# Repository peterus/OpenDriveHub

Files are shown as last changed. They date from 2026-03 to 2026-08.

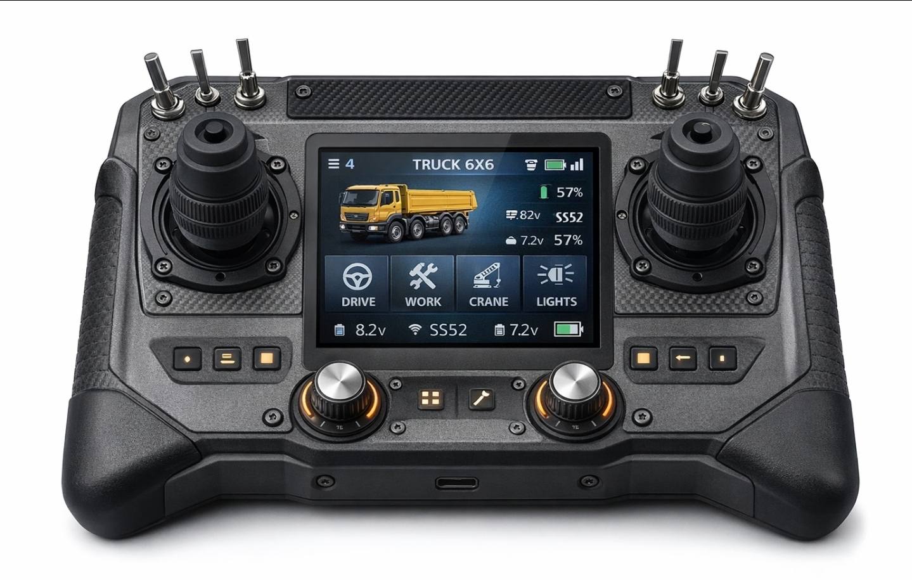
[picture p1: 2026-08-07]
hardware/transmitter/example_transmitter.jpg

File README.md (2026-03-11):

# OpenDriveHub

Open-source modular control platform for functional model vehicles (excavators,
dump trucks, tractors, and other ground-based RC models).

## Features

- **Modular transmitter** – plug-in front-panel slots for switches, buttons,
  potentiometers, and encoders; detected automatically at boot
- **I²C backplane** with TCA9548A multiplexer – identical standard I²C devices
  in every slot, no address conflicts, no MCU needed on modules
- **Always-on bidirectional telemetry** – battery voltage, RSSI, link state,
  and custom sensor values returned from the model
- **ESP32-based** firmware using PlatformIO + Arduino + FreeRTOS
- **Modern C++20** – `namespace odh`, `enum class`, `constexpr`, `std::optional`,
  RAII wrappers, shared libraries
- **ESP-NOW radio link** – low-latency, no router required
- **ILI9341 touch-screen display** – 320×240 colour LCD with XPT2046 resistive
  touch, LVGL widget UI for vehicle selection and live channel monitoring
- **PCA9685 servo driver** – I²C-based 16-channel PWM output on the receiver
- **Receiver-initiated discovery** – receivers broadcast their presence;
  the operator selects a vehicle on the transmitter touch screen
- **Vehicle model presets** – built-in function-to-channel maps for Generic,
  Dump Truck, Excavator, Tractor, and Crane models
- **Always-on web configuration** – WiFi AP + REST API (ESPAsyncWebServer +
  ArduinoJson v7) on both transmitter and receiver; starts automatically at
  boot, no button required; settings stored in ESP32 NVS
- **Linux simulation** – full transmitter + receiver simulation on a PC; SDL2
  display window, keyboard channel control, UDP radio loopback
- **Open hardware + firmware** under GPL-3.0

## Repository Structure

```
OpenDriveHub/
├── firmware/                   # Unified PlatformIO project (C++20, namespace odh::)
│   ├── platformio.ini          # Build config for all 5 environments
│   ├── lib/                    # Shared libraries
│   │   ├── odh-protocol/      # Packet definitions & function mapping
│   │   ├── odh-config/        # Compile-time configuration & NVS store
│   │   ├── odh-radio/         # ESP-NOW radio link (TX + RX)
│   │   ├── odh-telemetry/     # Battery monitor & telemetry data
│   │   └── odh-web/           # ESPAsyncWebServer + REST API helpers
│   ├── src/
│   │   ├── receiver/          # Receiver app (OutputManager, PCA9685, ReceiverApi)
│   │   └── transmitter/       # Transmitter app (Modules, Display, TransmitterApi)
│   ├── test/test_native/      # Native unit tests (90 tests, no hardware needed)
│   ├── data/                   # LittleFS web UI (receiver/ and transmitter/)
│   ├── include/                # LVGL & TFT_eSPI build-config headers
│   └── sim/                    # Linux simulation shims (SDL2, UDP, pthreads)
│       ├── include/            # Replacement headers (Arduino.h, esp_now.h, …)
│       └── src/                # Shim implementations
├── hardware/
│   ├── transmitter/            # Transmitter BOM and wiring reference
│   ├── receiver/               # Receiver BOM and wiring reference
│   └── modules/                # Per-module hardware documentation
│       ├── switch/
│       ├── button/
│       ├── potentiometer/
│       └── encoder/
└── docs/
    ├── index.md                # GitHub Pages one-pager
    ├── getting-started.md
    ├── architecture.md
    ├── backplane.md
    └── protocol.md
```

## Quick Start

See **[docs/getting-started.md](docs/getting-started.md)** for full build and
flash instructions.

```bash
cd firmware

# Flash transmitter
pio run -e transmitter -t upload

# Flash receiver
pio run -e receiver -t upload

# Run host-side unit tests (90 tests)
pio test -e native
```

### Run the simulation (no hardware needed)

```bash
cd firmware

# Terminal 1 – receiver
pio run -e sim_rx -t exec

# Terminal 2 – transmitter (headless terminal simulation)
pio run -e sim_tx -t exec
```

See **[firmware/sim/README.md](firmware/sim/README.md)** for full simulation docs.

## Supported Module Types

| Module | I²C Device | Channels |
|---|---|---|
| Switch (toggle) | PCF8574 @ 0x20 | 8 |
| Button (momentary) | PCF8574 @ 0x21 | 8 |
| Potentiometer / fader | ADS1115 @ 0x48 | 4 |
| Encoder (absolute) | AS5600 @ 0x36 | 1 |

## Documentation

- [Getting Started](docs/getting-started.md)
- [System Architecture](docs/architecture.md)
- [Backplane & Modules](docs/backplane.md)
- [Radio Protocol](docs/protocol.md)
- [Transmitter Hardware](hardware/transmitter/README.md)
- [Receiver Hardware](hardware/receiver/README.md)
- [Simulation](firmware/sim/README.md)

## License

GPL-3.0 – see [LICENSE](LICENSE).

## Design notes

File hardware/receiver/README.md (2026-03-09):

# Receiver Hardware

The OpenDriveHub receiver is mounted in a vehicle and drives servos / ESCs
via a **PCA9685** I²C PWM driver.  It runs on an **ESP32** development board.

---

## Block Diagram

```
                  ┌─────────────────────┐
         I²C     │    ESP32-DevKitC     │
  ┌──────────────┤ SDA=21  SCL=22      │
  │              │                      │
  │              │ GPIO34 (ADC) ← Batt  │
  │              │                      │
  │              │ GPIO0 ← Config btn   │
  │              └─────────────────────┘
  │
  ├── PCA9685 (0x40)
  │     ├── CH0 → Servo / ESC 0
  │     ├── CH1 → Servo / ESC 1
  │     ├── …
  │     └── CH7 → Servo / ESC 7
  │
  └── (pull-ups 4k7 to 3V3)
```

---

## Bill of Materials

| Qty | Component | Notes |
|-----|---|---|
| 1 | ESP32-DevKitC (or equivalent) | 38-pin recommended |
| 1 | PCA9685 16-channel PWM driver | Adafruit 815 or generic breakout |
| 2 | 4.7 kΩ resistors | I²C pull-ups on SDA / SCL |
| 1 | Voltage divider (100 kΩ + 33 kΩ) | Battery ADC on GPIO34 |
| 1 | 5 V BEC / regulator | Servo power supply |
| n | Servos or ESCs | Up to 8 channels (default) |

---

## GPIO Pinout

### I²C Bus

| GPIO | Function |
|---|---|
| 21 | SDA |
| 22 | SCL |

The PCA9685 connects to this bus at address **0x40**
(`odh::config::rx::kPca9685Addr`).

### Battery ADC

| GPIO | Function |
|---|---|
| 34 | Battery voltage via divider |

### Config Button (optional)

| GPIO | Function |
|---|---|
| 0 | Config mode trigger (active LOW, internal pull-up) |

> **Note:** The web configuration AP starts automatically at every boot.
> The config button is reserved for future use (e.g. factory reset).

---

## PCA9685 Wiring

The PCA9685 board has its own power input for the servo rail (usually
labelled **V+**).  This must be supplied by an appropriate BEC or regulator
(typically 5 V / 6 V depending on your servos).  The logic side is powered
by 3.3 V from the ESP32.

| PCA9685 Pin | Connects to |
|---|---|
| VCC | ESP32 3V3 |
| GND | ESP32 GND + servo GND |
| SDA | ESP32 GPIO21 |
| SCL | ESP32 GPIO22 |
| V+ | BEC 5 V (servo power) |
| OE | Leave unconnected or tie LOW (outputs enabled) |

Servo signal wires connect to the PCA9685 output headers (CH0–CH7).

---

## Programming

```bash
cd firmware
pio run -e receiver -t upload
pio run -e receiver -t monitor   # 115200 baud
```

---

## WiFi Configuration

The receiver starts a WiFi AP automatically at every boot:

- **SSID:** `ODH-Receiver-Config` (configurable in `odh::config::rx::kWebApSsid`)
- **Password:** `odhrecv1` (configurable in `odh::config::rx::kWebApPass`)

Open `http://192.168.4.1` in a browser to access the web UI.

REST API endpoints:
- `GET /api/status` – link state, battery, vehicle name
- `GET /api/config` – vehicle name, model type
- `POST /api/config` – update vehicle settings (JSON body)
- `GET /api/mapping` – current function→channel mapping
- `POST /api/mapping` – update mapping (JSON body)

---

## Binding (Discovery)

The receiver uses **receiver-initiated discovery**:

1. On power-up (and whenever disconnected), the receiver broadcasts an
   `odh::AnnouncePacket` every 500 ms containing its vehicle name and
   model type.
2. A transmitter in scanning mode receives the announcement and displays
   the vehicle on its LCD.
3. When the user selects this vehicle, the transmitter sends a
   `odh::BindPacket` to the receiver's MAC address.
4. The receiver transitions to **Connected** and begins accepting
   `ControlPacket` data.

---

## Failsafe

If no `ControlPacket` is received within `odh::config::kRadioFailsafeTimeoutMs`
(default **500 ms**):

- All output channels are set to `odh::config::kFailsafeChannelValue`
  (default **1500 µs** = center / neutral).
- The receiver reports `LinkState::Failsafe` in its telemetry.

If the link remains lost for `odh::config::kRadioLinkTimeoutMs`
(default **3000 ms**), the receiver returns to **Disconnected** and resumes
broadcasting announcements.

---

## Output Channels

The default channel count is **8** (`odh::config::rx::kChannelCount`).  The
PCA9685 hardware supports up to 16 channels – increase this constant and
connect additional servos as needed.

Each channel receives a PWM signal in the standard RC range:
- **1000 µs** = full reverse / minimum
- **1500 µs** = center / neutral
- **2000 µs** = full forward / maximum

The `OutputManager` maps incoming `odh::FunctionValue` entries to physical
PCA9685 channels using the function→channel mapping (configurable via the
web UI or `odh::defaultFunctionMap()`).

---

## Configuration Reference

All receiver constants are in `firmware/lib/odh-config/Config.h` under the
`odh::config::rx` namespace.

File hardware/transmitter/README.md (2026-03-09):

# Transmitter Hardware

The OpenDriveHub transmitter is a hand-held controller built around an
**ESP32** development board.

---

## Block Diagram

```
                  ┌─────────────────────┐
         I²C     │    ESP32-DevKitC     │  SPI
  ┌──────────────┤ SDA=21  SCL=22      ├────────────┐
  │              │                      │            │
  │              │ GPIO34 (ADC) ← Batt  │    ┌───────┴───────┐
  │              │                      │    │  ILI9341 LCD  │
  │              │ MOSI=23 MISO=19      │    │  320×240      │
  │              │ SCK=18  CS=5         │    │  + XPT2046    │
  │              │ DC=27   RST=26       │    │    Touch      │
  │              │ BL=32   T_CS=4       │    └───────────────┘
  │              │ T_IRQ=33             │
  │              └─────────────────────┘
  │
  ├── TCA9548A (0x70)
  │     ├── CH0 → Slot 0
  │     ├── CH1 → Slot 1
  │     ├── …
  │     └── CH5 → Slot 5
  │
  └── (pull-ups 4k7 to 3V3)
```

---

## Bill of Materials

| Qty | Component | Notes |
|-----|---|---|
| 1 | ESP32-DevKitC (or equivalent) | 38-pin recommended |
| 1 | ILI9341 SPI LCD 320×240 | 2.4″ or 2.8″ breakout |
| 1 | XPT2046 resistive touch controller | Usually integrated on LCD board |
| 1 | TCA9548A I²C multiplexer breakout | Adafruit 2717 or generic |
| 2 | 4.7 kΩ resistors | I²C pull-ups on SDA / SCL |
| 1 | Voltage divider (100 kΩ + 33 kΩ) | Battery ADC on GPIO34 |
| 1 | 2S LiPo battery (7.4 V) | Optional – can be USB-powered |
| 6 | 4-pin headers / connectors | Module slot connectors |

---

## GPIO Pinout

### SPI Display (ILI9341)

| GPIO | Function |
|---|---|
| 23 | MOSI (SDI) |
| 19 | MISO (SDO) |
| 18 | SCK |
| 5 | CS (chip select) |
| 27 | DC (data / command) |
| 26 | RST (reset) |
| 32 | Backlight (active high) |

### Touch (XPT2046)

| GPIO | Function |
|---|---|
| 4 | T_CS (touch chip select) |
| 33 | T_IRQ (touch interrupt) |

SPI bus is shared between LCD and touch.

### I²C Bus

| GPIO | Function |
|---|---|
| 21 | SDA |
| 22 | SCL |

All modules and the TCA9548A mux share this bus at 400 kHz.

### Battery ADC

| GPIO | Function |
|---|---|
| 34 | Battery voltage via divider |

Divider ratio: `odh::config::kBatteryDividerRatio` (default 4.03).

---

## Programming

```bash
cd firmware
pio run -e transmitter -t upload
pio run -e transmitter -t monitor   # 115200 baud
```

---

## WiFi Configuration

The transmitter starts a WiFi AP automatically at every boot:

- **SSID:** `OpenDriveHub-Config` (configurable in `odh::config::tx::kWebApSsid`)
- **Password:** `opendrv1` (configurable in `odh::config::tx::kWebApPass`)

Open `http://192.168.4.1` in a browser to access the web UI.

REST API endpoints:
- `GET /api/status` – link state, battery, RSSI
- `GET /api/modules` – detected modules per slot
- `GET /api/mapping` – current function→channel mapping
- `POST /api/mapping` – update mapping (JSON body)

---

## Module Slot Connector

Each slot provides a **4-pin header**:

| Pin | Signal |
|-----|---|
| 1 | 3V3 |
| 2 | GND |
| 3 | SDAn |
| 4 | SCLn |

SDAn / SCLn are the TCA9548A downstream channel pins for that slot.

---

## Enclosure Considerations

- The LCD needs a rectangular cutout of approximately 50 × 35 mm (varies by
  breakout board).
- Leave openings or slots on the sides for module headers.
- The USB port should remain accessible for firmware updates.
- A power switch between the battery and the 3V3 regulator is recommended.

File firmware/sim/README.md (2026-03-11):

# Simulation

OpenDriveHub includes three simulation environments that build the full
firmware as **Linux executables**.  No ESP32 hardware is required.

---

## Quick Start

### Prerequisites

```bash
# SDL2 is needed only for the sim_tx_gui environment (display window)
sudo apt install pkg-config libsdl2-dev
```

### Running

```bash
cd firmware

# Receiver simulation (terminal-only, no display)
pio run -e sim_rx -t exec

# Transmitter simulation (headless terminal, no display)
pio run -e sim_tx -t exec

# Transmitter simulation with SDL2 GUI (opens a window)
pio run -e sim_tx_gui -t exec
```

Open both in separate terminals to simulate a complete TX → RX link.

---

## What Is Simulated

The sim layer replaces every hardware-specific API with a software shim.
Source files live in `firmware/sim/`.

| Real Hardware | Shim Header | Shim Source | Approach |
|---|---|---|---|
| ESP-NOW radio | `esp_now.h` | `sim_espnow.cpp` | UDP multicast on localhost |
| FreeRTOS | `freertos/FreeRTOS.h`, `task.h`, `semphr.h` | `sim_freertos.cpp` | pthreads, BSD timers |
| I²C (Wire) | `Wire.h` | `sim_wire.cpp` | In-memory virtual bus |
| ADS1115 | `Adafruit_ADS1X15.h` | (header-only stub) | Returns constant mid-value |
| PCF8574 | `Adafruit_PCF8574.h` | (header-only stub) | Returns 0xFF (all high) |
| Preferences (NVS) | `Preferences.h` | `sim_preferences.cpp` | In-memory key-value map |
| ILI9341 + LVGL | `TFT_eSPI.h` | (linked SDL2) | SDL2 window (sim_tx_gui only) |
| WiFi AP | `WiFi.h` | `sim_wifi.cpp` | No-op (AP name printed) |
| ESPAsyncWebServer | `ESPAsyncWebServer.h` | `sim_webserver.cpp` | Localhost HTTP |
| LittleFS | `LittleFS.h` | (header-only stub) | No-op |
| Arduino core | `Arduino.h` | `sim_arduino.cpp` | `millis()`, `delay()`, `Serial` |
| Keyboard input | `sim_keyboard.h` | `sim_keyboard.cpp` | SDL2 key events (sim_tx_gui) |

---

## Connection Flow (in simulation)

1. Start `sim_rx` — it immediately begins broadcasting `AnnouncePacket` via
   UDP.
2. Start `sim_tx` — the transmitter runs in headless mode in the terminal.
   Alternatively, start `sim_tx_gui` — an SDL2 window appears showing the scan screen.
3. After a few seconds the receiver's vehicle name appears on screen.
4. Click the vehicle button in the SDL2 window to bind (sim_tx_gui), or the
   transmitter auto-connects in headless mode (sim_tx).
5. Both sides enter **Connected** state.  Control packets flow TX → RX;
   telemetry flows RX → TX.

---

## Keyboard Shortcuts (sim_tx_gui)

The transmitter simulation accepts keyboard input to control function values
instead of physical modules.

| Key | Action |
|-----|---|
| `1` – `8` | Select active channel |
| `↑` / `↓` | Increase / decrease value by 10 µs |
| `Page Up` / `Page Down` | Increase / decrease value by 100 µs |
| `Home` | Center active channel (1500 µs) |
| `Space` | Center ALL channels |
| `Esc` / close window | Quit |

---

## Web UI in Simulation

Both environments start a local HTTP server:

| Environment | URL | Port |
|---|-----|---|
| sim_tx | http://localhost:8080 | 8080 |
| sim_tx_gui | http://localhost:8080 | 8080 |
| sim_rx | http://localhost:8081 | 8081 |

> **Note:** Static files (HTML/CSS/JS) are **not** served in simulation
> because LittleFS is stubbed.  Only the REST API endpoints (`/api/…`) are
> functional.

---

## Configuration Constants in Simulation

All compile-time constants come from `firmware/lib/odh-config/Config.h` and
apply identically in simulation.  Key values:

| Constant | Namespace | Default |
|---|---|---|
| `kRadioFailsafeTimeoutMs` | `odh::config` | 500 ms |
| `kRadioLinkTimeoutMs` | `odh::config` | 3000 ms |
| `kVehicleDiscoveryTimeoutMs` | `odh::config::tx` | 5000 ms |
| `kRadioWifiChannel` | `odh::config` | 1 |
| `kControlLoopIntervalMs` | `odh::config::tx` | 20 ms (50 Hz) |
| `kAnnounceIntervalMs` | `odh::config::rx` | 500 ms |

---

## Build System

The simulation environments are defined in `firmware/platformio.ini` and
extend the `[esp32_base]` configuration with `platform = native`.  A custom
build script (`firmware/sim/sim_build.py`) adds:

- `-I firmware/sim/include` (shim headers)
- Linking of shim `.cpp` sources
- SDL2 flags via `pkg-config` (sim_tx_gui only)
- `-DNATIVE_SIM` preprocessor define

---

## Known Limitations

- **No real WiFi** – the WiFi AP is a no-op; only localhost HTTP works.
- **No persistent storage** – `Preferences` (NVS) data is lost on exit.
- **No I²C devices** – Wire reads return 0; module stubs return default
  values (mid-range for pots, 0xFF for digital I/O).
- **Static files not served** – LittleFS is stubbed; REST API endpoints
  work but the HTML/CSS/JS web UI does not load.
- **Single machine only** – UDP radio uses `127.0.0.1`; cross-machine
  simulation is not supported.

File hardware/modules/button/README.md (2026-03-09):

# Button Module

## Overview

The button module provides **8 independent momentary push-button inputs** via a
PCF8574 I²C GPIO expander.  It is electrically identical to the switch module
but uses I²C address **0x21** (A0 tied HIGH), allowing it to coexist with a switch
module on the same PCB or be distinguished during slot scanning.

---

## Hardware

| Component | Part | Notes |
|---|---|---|
| 1× | PCF8574AP (DIP-16) or PCF8574T (SO-16) | I²C GPIO expander, 0x21 |
| 8× | Momentary tactile push-button | SPST-NO, close to GND |
| 1× | 100 nF capacitor | Bypass on VCC pin |
| 1× | 4-pin JST-SH connector | Matches transmitter slot connector |

**I²C address:** A0 tied to 3V3, A1–A2 tied to GND → **0x21**

---

## Circuit

```
Slot connector:
  GND ─────── GND (PCF8574 pin 8, all button commons)
  3V3 ─────── VCC (PCF8574 pin 16) ── 100 nF ── GND
  SDA ─────── SDA (PCF8574 pin 15)
  SCL ─────── SCL (PCF8574 pin 1)

Address pins:
  A0 (pin 1) → 3V3
  A1 (pin 2) → GND
  A2 (pin 3) → GND

Each input:
  PCF8574 Px pin ── Button ── GND
```

---

## Firmware Behaviour

- Button **pressed** → Px low → channel **2000 µs** (MAX)
- Button **released** → Px high → channel **1000 µs** (MIN)

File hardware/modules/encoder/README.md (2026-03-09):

# Encoder Module

## Overview

The encoder module provides **one absolute rotary encoder input** using an AS5600
12-bit contactless magnetic position sensor.  The encoder reports a true absolute
angle (0–4095 per revolution) with no count accumulation or overflow.

---

## Hardware

| Component | Part | Notes |
|---|---|---|
| 1× | AS5600 (SOIC-8) or breakout board | Magnetic encoder, fixed address 0x36 |
| 1× | Diametrically magnetised disc magnet | 6 mm × 2.5 mm, N/S through diameter |
| 1× | Rotary shaft / knob | Must hold the magnet centred above AS5600 |
| 1× | 100 nF capacitor | AS5600 VDD bypass |
| 1× | 4-pin JST-SH connector | Matches transmitter slot connector |

**I²C address:** Fixed at **0x36** (not configurable).

---

## Circuit

```
Slot connector:
  GND ─────── GND (AS5600)
  3V3 ─────── VDD (AS5600) ── 100 nF ── GND
  SDA ─────── SDA (AS5600)
  SCL ─────── SCL (AS5600)

  DIR pin → GND   (clockwise = increasing angle)
```

The AS5600 has no address-select pin.  Because the backplane mux gives each slot its
own I²C channel, address conflicts between multiple encoder modules in different slots
are automatically avoided.

---

## Magnet Placement

Mount the diametrically magnetised disc magnet on the encoder shaft, centred directly
above the AS5600 IC, with a gap of **0.5–3 mm**.  The magnet must be parallel to the
IC surface.  An alignment LED on the AS5600 breakout indicates correct field strength.

---

## Firmware Behaviour

- Reads the **ANGLE** register (0x0C/0x0D, 12-bit) in every `update()` call.
- Raw angle 0 → channel **1000 µs** (MIN)
- Raw angle 4095 → channel **2000 µs** (MAX)
- Linear mapping, no filtering applied by default.

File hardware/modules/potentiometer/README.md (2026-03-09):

# Potentiometer Module

## Overview

The potentiometer module provides **4 analogue inputs** using an ADS1115 16-bit ADC.
Typical applications: joystick axes, throttle levers, trim knobs, faders.

---

## Hardware

| Component | Part | Notes |
|---|---|---|
| 1× | ADS1115 (SSOP-10) or breakout board | 16-bit ADC, 0x48 |
| 1–4× | 10 kΩ linear potentiometer | B10K, mono |
| 1× | 100 nF capacitor | ADS1115 VDD bypass |
| 1× | 4-pin JST-SH connector | Matches transmitter slot connector |

**I²C address:** ADDR pin tied to GND → **0x48**

---

## Circuit

```
Slot connector:
  GND ─────── GND (ADS1115 GND, all pot wipers and low ends)
  3V3 ─────── VDD (ADS1115) ── 100 nF ── GND
  SDA ─────── SDA (ADS1115)
  SCL ─────── SCL (ADS1115)

  ADDR (pin 1) → GND   (address 0x48)

Potentiometer wiring (×4):
  3V3 ──────── pot high end
  GND ──────── pot low end
  AINx ─────── pot wiper (AIN0 for ch1, AIN1 for ch2, …)
```

---

## Firmware Behaviour

- ADS1115 is configured for **±4.096 V range, single-ended, 860 SPS**.
- Each channel is read sequentially in single-shot mode.
- Raw ADC value 0 → channel **1000 µs** (MIN)
- Raw ADC value 32767 → channel **2000 µs** (MAX)
- Values are linearly mapped; no deadband is applied by default.

---

## Notes

- The ESP32 supply is 3.3 V, so pots will not reach full ADS1115 input range
  (±4.096 V).  Maximum input ≈ 3.3 V → raw value ≈ 26428.
  The firmware maps the full 0–32767 range regardless; adjust `POT_ADC_MAX`
  in `PotModule.h` to match your supply if you need full-range calibration.
- ADS1115 is 5 V tolerant on inputs – a 5 V supply for pots is also acceptable.

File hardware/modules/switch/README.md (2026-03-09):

# Switch Module

## Overview

The switch module provides **8 independent toggle switch inputs** via a single
PCF8574 I²C GPIO expander.  It plugs into any transmitter slot on the backplane.

Because the backplane multiplexer isolates each slot to its own I²C channel,
every switch module uses the same default PCF8574 address (0x20) without conflict.

---

## Hardware

| Component | Part | Notes |
|---|---|---|
| 1× | PCF8574AP (DIP-16) or PCF8574T (SO-16) | I²C GPIO expander, 0x20 |
| 8× | SPDT toggle switch | Or SPST – one terminal to GND, other to GPIO pin |
| 8× | 10 kΩ resistor (optional) | External pull-up (PCF8574 has weak internal pull-ups ~100 µA) |
| 1× | 100 nF capacitor | Bypass on VCC pin |
| 1× | 4-pin JST-SH connector | Matches transmitter slot connector |

**I²C address:** A0–A2 all tied to GND → **0x20**

---

## Circuit

```
Slot connector:
  GND ─────── GND (PCF8574 pin 8, all switch commons)
  3V3 ─────── VCC (PCF8574 pin 16) ── 100 nF ── GND
  SDA ─────── SDA (PCF8574 pin 15)
  SCL ─────── SCL (PCF8574 pin 1)

Each input:
  PCF8574 Px pin ── Switch ── GND
  (switch open → Px high via internal pull-up; switch closed → Px low)
```

Address pins:
```
  A0 (pin 1) → GND
  A1 (pin 2) → GND
  A2 (pin 3) → GND
```

---

## Firmware Behaviour

- Bit = **0** in the PCF8574 byte: switch **closed** → channel **2000 µs** (MAX)
- Bit = **1** in the PCF8574 byte: switch **open** → channel **1000 µs** (MIN)

Each switch maps to one logical channel in the order P0–P7.

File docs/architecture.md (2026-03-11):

# Architecture

OpenDriveHub consists of a **transmitter** (hand-held controller) and a
**receiver** (vehicle-mounted).  They communicate over ESP-NOW, a
connectionless, low-latency IEEE 802.11 protocol.

Both devices run on ESP32 and share a common set of libraries.  The entire
firmware is built from a single PlatformIO project located in `firmware/`.

---

## High-Level Block Diagram

```
╭─────────────────────────────────────────────────────╮
│                   TRANSMITTER                       │
│                                                     │
│  ┌───────────┐  ┌────────────────┐  ┌───────────┐  │
│  │ Modules   │──│ ModuleManager  │──│ RadioLink │──┼──── ESP-NOW ────┐
│  │ (I²C via  │  └────────┬───────┘  └───────────┘  │                │
│  │  TCA9548A)│           │                          │                │
│  └───────────┘  ┌────────┴───────┐                  │                │
│                 │ TransmitterApp │                   │                │
│                 └────────┬───────┘                   │                │
│         ┌────────────────┼────────────────┐          │                │
│  ┌──────┴──────┐ ┌───────┴───────┐ ┌─────┴──────┐  │                │
│  │  Display    │ │ BatteryMonitor│ │ WebServer  │  │                │
│  │ (LVGL/LCD) │ │ (Telemetry)   │ │ + REST API │  │                │
│  └─────────────┘ └───────────────┘ └────────────┘  │                │
╰─────────────────────────────────────────────────────╯                │
                                                                       │
╭─────────────────────────────────────────────────────╮                │
│                    RECEIVER                         │                │
│                                                     │                │
│  ┌───────────┐  ┌────────────────┐  ┌───────────┐  │                │
│  │ PCA9685   │──│ OutputManager  │──│ RadioLink │──┼──── ESP-NOW ────┘
│  │ (I²C PWM) │  └────────┬───────┘  └───────────┘  │
│  └───────────┘           │                          │
│                 ┌────────┴───────┐                  │
│                 │  ReceiverApp   │                  │
│                 └────────┬───────┘                  │
│         ┌────────────────┼────────────────┐         │
│  ┌──────┴──────┐ ┌───────┴───────┐ ┌─────┴──────┐  │
│  │ Telemetry   │ │ BatteryMonitor│ │ WebServer  │  │
│  │ (announce / │ │               │ │ + REST API │  │
│  │  sensor)    │ └───────────────┘ └────────────┘  │
│  └─────────────┘                                    │
╰─────────────────────────────────────────────────────╯
```

---

## Directory Layout

```
firmware/
├── platformio.ini         # Unified build: receiver, transmitter, native, sim_rx, sim_tx, sim_tx_gui
├── lib/                   # Shared libraries (used by both targets)
│   ├── odh-protocol/      #   Protocol.h, FunctionMap.h
│   ├── odh-config/        #   Config.h, NvsStore.h (compile-time + NVS)
│   ├── odh-radio/         #   ReceiverRadioLink, TransmitterRadioLink
│   ├── odh-telemetry/     #   BatteryMonitor, TelemetryData
│   └── odh-web/           #   OdhWebServer, ApiHandler
├── src/
│   ├── receiver/          # Receiver application
│   │   ├── ReceiverApp.h/cpp
│   │   ├── OutputManager.h/cpp
│   │   ├── output/        # IOutputDriver, Pca9685Output, LoggingOutput
│   │   ├── web/           # ReceiverApi
│   │   └── main.cpp
│   └── transmitter/       # Transmitter application
│       ├── TransmitterApp.h/cpp
│       ├── backplane/     # Backplane (TCA9548A mux)
│       ├── display/       # Display (LVGL), display_utils
│       ├── modules/       # IModule, ModuleManager, 4 module types
│       ├── web/           # TransmitterApi
│       └── main.cpp
├── data/
│   ├── receiver/          # Static web UI (HTML/CSS/JS) for receiver
│   └── transmitter/       # Static web UI for transmitter
├── include/               # Board-level overrides (lv_conf.h, User_Setup.h)
├── sim/                   # Simulation shim headers for sim_rx / sim_tx / sim_tx_gui
└── test/
    └── test_native/       # Unity tests (90 cases)
```

---

## Shared Libraries (firmware/lib/)

Each library is self-contained and has no dependencies on application code.

| Library | Purpose | Key Types |
|---|---|---|
| **odh-protocol** | Radio protocol structs, enums, checksum utilities, function mapping | `odh::ControlPacket`, `odh::TelemetryPacket`, `odh::BindPacket`, `odh::AnnouncePacket`, `odh::FunctionValue`, `odh::Function`, `odh::PacketType`, `odh::ModelType`, `odh::LinkState` |
| **odh-config** | Compile-time constants and NVS persistence | `odh::config::*`, `odh::config::rx::*`, `odh::config::tx::*`, `odh::NvsStore` |
| **odh-radio** | ESP-NOW radio link abstraction | `odh::ReceiverRadioLink`, `odh::TransmitterRadioLink` |
| **odh-telemetry** | Battery monitoring and telemetry data | `odh::BatteryMonitor`, `odh::TelemetryData` |
| **odh-web** | HTTP server and REST API helpers | `odh::OdhWebServer`, `odh::ApiHandler` |

---

## Transmitter Software Layers

### FreeRTOS Tasks

| Task | Core | Priority | Rate | Purpose |
|---|---|---|---|---|
| Control | 1 | 3 | 50 Hz | Module scan → packet build → radio TX |
| Display | 0 | 1 | ~4 Hz | LVGL tick → screen repaint (scan / control) |
| Web | 0 | 1 | async | ESPAsyncWebServer – REST API + static files |

### Application Flow

1. **`main.cpp`** constructs a `TransmitterApp` and creates FreeRTOS tasks.
2. **`TransmitterApp`** owns `ModuleManager`, `Display`, `TransmitterRadioLink`,
   `BatteryMonitor`, `OdhWebServer`, and `TransmitterApi`.
3. **`ModuleManager`** scans each slot through the **`Backplane`** (TCA9548A mux)
   and instantiates the detected **`IModule`** implementation:
   - `PotModule` (ADS1115 – 16-bit analog, 0x48)
   - `SwitchModule` (PCF8574 – 8-bit I/O expander, 0x20)
   - `ButtonModule` (PCF8574 – 8-bit I/O expander, 0x21)
   - `EncoderModule` (AS5600 – magnetic rotary encoder, 0x36)
4. Each module produces a `FunctionValue` array that is packed into
   an `odh::ControlPacket` and dispatched to the `TransmitterRadioLink`.
5. **`Display`** drives the ILI9341 LCD via LVGL.  It has two screens:
   - *Scan screen* – shows discovered vehicles; tap to bind
   - *Control screen* – channel bars, trim values, telemetry (battery, RSSI)
6. **`TransmitterApi`** (via `OdhWebServer` + `ApiHandler`) exposes:
   - `GET /api/status` – link state, battery, RSSI
   - `GET /api/modules` – detected module list
   - `GET /api/mapping` – function→channel map
   - `POST /api/mapping` – update function map
   - Static files from LittleFS `/transmitter/`

### Module Detection

When a slot is selected via `Backplane::selectSlot(n)`, the `ModuleManager`
probes known I²C addresses:

| Address | Chip | Module |
|---|---|---|
| 0x48 | ADS1115 | `PotModule` |
| 0x20 | PCF8574 | `SwitchModule` |
| 0x21 | PCF8574 | `ButtonModule` |
| 0x36 | AS5600 | `EncoderModule` |

If no known device responds, the slot is marked empty.

---

## Receiver Software Layers

### FreeRTOS Tasks

| Task | Core | Priority | Rate | Purpose |
|---|---|---|---|---|
| Output | 1 | 3 | continuous | Apply latest function values to PCA9685 |
| Telemetry | 0 | 1 | 10 Hz | Build + send `TelemetryPacket` back to TX |
| Web | 0 | 1 | async | ESPAsyncWebServer – REST API + static files |

### Application Flow

1. **`main.cpp`** constructs a `ReceiverApp` and creates FreeRTOS tasks.
2. **`ReceiverApp`** owns `OutputManager`, `ReceiverRadioLink`,
   `BatteryMonitor`, `TelemetryData`, `OdhWebServer`, and `ReceiverApi`.
3. **`ReceiverRadioLink`**:
   - In **Disconnected** state, periodically broadcasts an `AnnouncePacket`
     with the vehicle name and model type so that transmitters can discover it.
   - On receiving a `BindPacket`, transitions to **Connected** and starts
     accepting `ControlPacket` data.
   - On timeout (`kRadioFailsafeTimeoutMs`), enters **Failsafe** and
     applies safe channel values.
4. **`OutputManager`** routes incoming `FunctionValue[]` to the appropriate
   **`IOutputDriver`**:
   - `Pca9685Output` – writes PWM pulse widths to a PCA9685 I²C PWM driver
   - `LoggingOutput` – debug fallback that logs values to serial
5. **`ReceiverApi`** (via `OdhWebServer` + `ApiHandler`) exposes:
   - `GET /api/status` – link state, battery, vehicle name
   - `GET /api/mapping` – function→channel map
   - `POST /api/mapping` – update function map
   - `GET /api/config` – vehicle name, model type
   - `POST /api/config` – update vehicle settings
   - Static files from LittleFS `/receiver/`

---

## Protocol Summary

See `docs/protocol.md` for the full specification.

| Packet | Size | Direction | Rate |
|---|---|---|---|
| `ControlPacket` | 73 B | TX → RX | 50 Hz |
| `TelemetryPacket` | 30 B | RX → TX | 10 Hz |
| `BindPacket` | 11 B | TX → RX | on bind/disconnect |
| `AnnouncePacket` | 28 B | RX → broadcast | 2 Hz |

All packets share a common 6-byte header:

```
[magic0 'O'][magic1 'D'][version][type][sequence_lo][sequence_hi]
```

The last byte of every packet is an XOR checksum of all preceding bytes
(computed by `odh::checksum()`).

---

## Backplane

See `docs/backplane.md` for details on the TCA9548A-based I²C multiplexer
bus that connects input modules to the transmitter.

---

## Simulation

Three simulation environments (`sim_rx`, `sim_tx`, `sim_tx_gui`) build the full
firmware as a Linux executable.  Hardware peripherals are replaced by software shims:

| Hardware | Simulation Shim |
|---|---|
| ESP-NOW | UDP multicast on 127.0.0.1 |
| FreeRTOS | pthreads / BSD timers |
| I²C (Wire) | In-memory virtual bus |
| Preferences (NVS) | In-memory key-value store |
| ILI9341 LCD + LVGL | SDL2 window (sim_tx_gui only) |
| PCA9685 / ADS1115 | Console logging |
| WiFi / WebServer | Localhost HTTP |

```bash
cd firmware
pio run -e sim_rx -t exec       # receiver simulation
pio run -e sim_tx -t exec       # transmitter simulation (headless terminal)
pio run -e sim_tx_gui -t exec   # transmitter simulation (SDL2 window)
```

See `firmware/sim/README.md` for keyboard shortcuts and known limitations.

---

## Build Environments

The unified `firmware/platformio.ini` defines six environments:

| Environment | Target | Board | Framework |
|---|---|---|---|
| `receiver` | ESP32 | esp32dev | Arduino |
| `transmitter` | ESP32 | esp32dev | Arduino |
| `native` | Host | native | — |
| `sim_rx` | Host (Linux) | native | — |
| `sim_tx` | Host (Linux) | native | — |
| `sim_tx_gui` | Host (Linux) | native | — |

Build commands:

```bash
cd firmware
pio run -e receiver              # build receiver
pio run -e transmitter           # build transmitter
pio test -e native               # run 90 unit tests
pio run -e sim_rx -t exec        # run receiver sim
pio run -e sim_tx -t exec        # run transmitter sim (headless)
pio run -e sim_tx_gui -t exec    # run transmitter sim (SDL2 window)
```

---

## C++20 Style

The codebase uses Modern C++ (ESP32 supports `gnu++2a`, native uses `gnu++20`):

- **`enum class`** for all protocol enums (`PacketType`, `ModelType`, `Function`, `LinkState`)
- **`inline constexpr`** for all compile-time constants (replaces `#define`)
- **`std::optional`** for nullable returns (e.g. NVS lookups)
- **`std::unique_ptr`** for owned polymorphic objects (modules, output drivers)
- **Interfaces** via pure virtual classes with `virtual ~I…() = default`
- **RAII wrappers** (e.g. `NvsStore` for `Preferences`)
- **`namespace odh`** used consistently throughout; no global pollution
- **`static_assert`** for compile-time packet size checks

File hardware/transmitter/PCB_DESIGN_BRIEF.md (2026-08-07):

# OpenDriveHub Transmitter — PCB Design Brief

Reference document for the parallel KiCad session. Pulls together the
component selection, mechanical envelope, signal architecture, and
layout positions that are already locked in by the case work.

Source of truth for **dimensions** is the OpenSCAD code in
`hardware/transmitter/parts/` and `hardware/transmitter/case/`. If a
number here disagrees with the .scad files, the .scad files win.

---

## 1. Project overview

DIY RC transmitter, "Mode 2" landscape format, ~286 × 136 mm panel.

- ESP32 controller (module choice TBD; ESP32-S3 WROOM-1 likely)
- 4.0" ST7796 IPS display (480×320) with FT6236 capacitive touch
- 2S LiPo, 2000 mAh nominal, USB-C charging via IP5389
- 7 sub-panel PCBs handling switches/buttons/encoders, fanned out via a
  TCA9548A I²C multiplexer on the main PCB so each sub-PCB sits on its
  own private downstream channel (all use the default PCF8574A address
  0x38 — no per-board jumpering, no collisions)
- 28 mm speaker (audio feedback / RX telemetry alarms)

The case shell is locked in (top + bottom shell, battery cover, battery
lid, USB-C panel-mount mount, etc.). The PCBs need to fit under the
existing panel cutouts and not collide with the corner bosses, side
walls, joystick bodies, or the battery compartment.

---

## 2. System architecture

```
                     ┌──────────────────────┐
                     │  USB-C female (ext.) │  AliExpress 17mm-pitch pigtail
                     └──────────┬───────────┘
                                │  (cable to main PCB)
                                ▼
   ┌─────────────────────────────────────────────────────────┐
   │  MAIN PCB                                               │
   │  ──────────────────────────────────────────────────     │
   │  · USB-C male plug socket (mates with extension)        │
   │  · IP5389 charger / boost controller (8.4V LiPo ↔ 5V)   │
   │  · 3.3V LDO/buck for ESP32 + I/O expanders              │
   │  · ESP32-S3 WROOM-1 module (or equivalent)              │
   │  · ST7796 display interface (SPI, direct from ESP32)    │
   │  · TCA9548A I²C multiplexer (1 upstream → 8 downstream) │
   │      ch 0..6: 7 sub-PCB headers (5-pin JST-XH each)     │
   │      ch 7   : FT6236 touch controller                   │
   │  · Audio amp (PAM8403 or similar) → 28mm speaker        │
   │  · 2× joystick ADC headers (5-pin: V, GND, X, Y, SW)    │
   │  · LiPo + balance connector (JST-XH 3-pin for 2S)       │
   └────┬────────────────────────────────────────────────────┘
        │ TCA9548A downstream channels (each is its own
        │ private I²C bus: 3.3V, GND, SDA, SCL + INT line)
        │
   ┌────┴────┬────────┬────────┬────────┬────────┬────────┐
   ▼         ▼        ▼        ▼        ▼        ▼        ▼
 toggle3  toggle3  illum3   illum3  encoder1 encoder1  nav3
 (-X top)(+X top)(-X bot)(+X bot) (-X bot) (+X bot)(centre bot)
```

All sub-PCBs carry a **PCF8574A** 8-bit I/O expander at the default
address **0x38** (A0=A1=A2 tied to GND on the sub-PCB silkscreen-and-
copper). Address conflicts are impossible because the TCA9548A on the
main PCB only enables one downstream channel at a time — every
sub-PCB lives in its own private bus segment. No per-board jumpering
required.

Each sub-PCB also exposes its PCF8574A's open-drain `/INT` pin to the
main PCB, so the firmware can sleep until input changes instead of
polling. Pull-up for `/INT` lives on the main PCB.

---

## 3. PCB list

| # | PCB | Qty | Purpose | Outline | Status |
| - | --- | --- | --- | --- | --- |
| 1 | `main` | 1 | brain, charging, display, audio, I²C mux | ~80 × 60 × 1.6 mm | TBD |
| 2 | `toggle3` | 2 | 3 long-bat toggles + PCF8574A | ~60 × 30 × 1.6 mm | TBD |
| 3 | `illum3` | 2 | 3 illuminated buttons + PCF8574A | ~60 × 30 × 1.6 mm | TBD |
| 4 | `encoder1` | 2 | 1 EC11 encoder + PCF8574A | ~30 × 30 × 1.6 mm | TBD |
| 5 | `nav3` | 1 | 3 tact buttons + PCF8574A | **32 × 30 × 1.6 mm** | **DONE** (`pcb/nav3/`) |

Sub-PCB footprints are estimates — the real bound is "must fit under
the corresponding panel cutout cluster, leave room for SOIC-16W IC
plus 4 corner mount holes plus a 5-pin JST-XH connector, and not poke
outside the case cavity". Cluster spans (X axis) from
`parts/layout_front.scad`:

- **toggle3**: 3 toggles 18 mm apart → 36 mm switch span; ~60 mm wide
- **illum3**: 3 illum buttons 18 mm apart → 36 mm span; ~60 mm wide
- **encoder1**: single encoder, ~12 × 12 mm body; ~30 mm both axes
- **nav3**: 3 tact buttons 10 mm apart → 20 mm switch span; 32 mm wide

**Sizing reality check from nav3** (the first board through KiCad):
the original 32 × 16 mm estimate was too short — the SOIC-16W body of
the PCF8574A on B.Cu plus 4× M2 corner mounts (3 mm inset) plus a
JST-XH 5-pin connector at one edge needed **32 × 30 mm**. Expect the
other sub-PCB outlines (especially encoder1 at "25 × 25") to grow
similarly when actually laid out.

Y-axis (height) of each sub-PCB: target ≤ 30 mm so the cluster fits
between panel and 27 mm of cavity (TOP_DEPTH 30 − PANEL_T 3 = 27 mm).
Sub-PCB sits 3-4 mm below the panel-mating face (the SUBPCB_Z_*
constants in `parts/layout_front.scad` are the source of truth);
component bodies hang below the PCB into the cavity.

**Connector** on each sub-PCB: 5-pin **JST-XH** 2.5 mm vertical header
(B5B-XH-A or equivalent), oriented so the cable exits toward the back
of the case. Pinout (matching nav3):

| Pin | Net |
|-----|---|
| 1 | 3V3 |
| 2 | GND |
| 3 | I2C_SDA  |
| 4 | I2C_SCL  |
| 5 | /INT |

**PCF8574A wiring** on each sub-PCB (default address 0x38):
- A0/A1/A2 hard-tied to GND
- 8 GPIO pins drive switch/button/encoder inputs to ground (internal
  weak pull-ups hold high at rest)
- /INT (open-drain) goes out on connector pin 5; pull-up lives on the
  main PCB
- 100 nF decoupling on VDD/VSS, 0805 metric (hand-solder friendly)

---

## 4. Component dimensions (footprint inputs for KiCad)

### 4.1 JH-D400X-R4 joystick (×2)

`parts/joystick.scad`:

- Base plate: 38 × 38 mm, 2 mm thick — 4 corner mount holes
- Body cylinder: Ø30 × 28 mm below the base
- Pin block: 20 × 8 × 6 mm extending below the body
- Pins: 5 (VCC, GND, X-pot, Y-pot, switch)
- Boot height above base: 9 mm
- Shaft length: 22 mm; knob Ø16, height 16 mm

Mount holes — see `JS_MOUNT_HOLE_D` and `JS_MOUNT_PITCH` in
`parts/joystick.scad` (verify in code).

Joystick is **above** the panel — connects to main PCB via 5-pin cable
(direct ADC, NOT through PCF8574).

### 4.2 Toggle switches — long-bat (×6)

Generic mini long-lever toggles, 3-position likely (ON-OFF-ON):

- Bushing: M6 (6 mm OD threaded), 8 mm panel-thread length
- Body below panel: ~13 × 8 × 17 mm
- Pins: 3 (common + 2 throws); 0.1 inch pitch typical

Verify with calipers — `parts/toggle_switch.scad` has the case-side
cutout dimensions.

### 4.3 EC11 rotary encoder + push (×2)

`parts/encoder.scad`:

- Body: 12 × 12 × 7 mm (typical EC11 family)
- Bushing: ~7 mm flat-flat, M7 thread
- Shaft: Ø6 × 20 mm, D-cut (`EC_SHAFT_FLAT = 0.5`)
- Pins: 5 — 3 for encoder (A, B, common) + 2 for push switch

PCB footprint with mounting tabs — standard EC11 footprint in
KiCad libraries.

### 4.4 Illuminated buttons (×6)

Round momentary, panel-mount, with built-in LED:

- Bushing: M12 thread typical (verify), Ø16 cap
- Body length below panel: ~15 mm
- Pins: 4 (switch contacts ×2, LED anode, LED cathode)

`parts/button_illuminated.scad` for cutout dim.

### 4.5 Nav tact buttons (×3)

6 × 6 mm tact (12 mm centerline pitch on `nav3` PCB; 10 mm in case
layout, see open question below):

- Body: 6 × 6 × 5 mm SMD or THT
- Cap: Ø4-5 mm above panel
- Pins: 4 (2 pairs internally connected)

`parts/button_tact.scad`. Surface-mount preferred for low profile.

### 4.6 Display — 4.0" ST7796 IPS + FT6236 touch (×1)

- Module: ~99 × 64 × 5 mm including components
- Visible area: ~85 × 56 mm
- Interface: ST7796 = SPI (4-wire SPI + DC + RESET); FT6236 = I2C
- Mount: usually 4 corner holes M2 or M2.5

`parts/display.scad` for current footprint and panel cutout.

The display module typically comes pre-assembled with both controllers
on a single PCB; main PCB just provides FFC connector or wire harness.

### 4.7 USB-C female extension cable (×1)

`parts/usb_c_extension_cable.scad`:

- Pigtail: USB-C female (panel mount) on one end → USB-C male plug on
  the other, ~20 cm of cable in between
- Panel-mount housing: 22 × 9 × 5 mm
- 2 × M2 screw holes at **17 mm pitch** (built into the housing)
- USB 2.0 only (D+, D-, VBUS, GND, CC1, CC2)

The MAIN PCB has a regular USB-C female connector that the male end
of this pigtail plugs into. KiCad library entry: standard USB-C
receptacle (SMD, 16-pin or 24-pin depending on USB-PD support
requirements).

### 4.8 Speaker

- 28 mm round, ~5 mm thick incl. magnet
- 8 Ω, 0.5-1 W
- Wire connection (solder pads on speaker)

Mount to back panel of bottom shell (TBD position — deferred).

### 4.9 LiPo battery (×1)

`parts/parameters.scad` `BATT_BODY = [80, 35, 15]`:

- 2S, 2000 mAh nominal
- Body: 80 × 35 × 15 mm pouch
- Power leads: 18 AWG silicone (red/black) at 6 mm centerline
- Balance connector: JST-XH 3-pin (2S) at 10 mm Y-offset

Connectors on main PCB:
- 2-pin power (XT30 or solder pads)
- 3-pin balance (JST-XH)

### 4.10 IP5389 charging IC

- USB-C input, supports up to 18W USB-PD charging
- 2-cell LiPo charge management
- 5V boost output (for any 5V loads on main PCB)
- QFN package, multiple support components (inductor, MOSFETs,
  bypass caps) — see Injoinic IP5389 datasheet/reference design

### 4.11 ESP32

ESP32-S3-WROOM-1 (recommended) or ESP32-WROOM-32E:

- 18 × 25 mm module footprint
- Castellated edge pads
- Built-in PCB antenna or U.FL connector for external

S3 has native USB so the USB-C port can also be used for serial /
firmware upload directly to the ESP32 without an external USB-UART.

### 4.12 PCF8574A I/O expanders (×7)

- 8-bit I/O expander, I²C interface
- Default address **0x38** (A0=A1=A2 to GND on every sub-PCB — no
  per-board configuration; the TCA9548A on the main PCB isolates each
  sub-PCB on its own bus segment)
- SOIC-16W (`Package_SO:SOIC-16W_7.5x10.3mm_P1.27mm`) — large enough
  to hand-solder, large enough to drive sub-PCB minimum height
- Open-drain `/INT` pin out → connector pin 5 on every sub-PCB
- 100 nF X7R 0805 decoupling cap right next to VDD/VSS

### 4.13 TCA9548A I²C multiplexer (main PCB)

- 8-channel I²C switch
- Address 0x70 (configurable via A0/A1/A2 if needed)
- Each downstream channel gets its own 4.7 kΩ SDA/SCL pull-ups on the
  main PCB (PCF8574A pull-ups on the sub-PCBs are too weak)
- Drives 7 sub-PCB connectors + 1 channel for the FT6236 touch IC
- TSSOP-24 package, 3.3V supply

---

## 5. Layout positions (from `parts/layout_front.scad`)

Coordinates in panel-mating-face-centred system, units mm, +X right,
+Y up:

| Component | Center positions |
| --- | --- |
| Display | (0, 12) |
| Joystick L | (-85, 12) |
| Joystick R | (+85, 12) |
| Toggle row Y | 45 |
| Toggle L (×3) | (-120, 45) (-102, 45) (-84, 45) |
| Toggle R (×3) | (+84, 45) (+102, 45) (+120, 45) |
| Illum row Y | -32 |
| Illum L (×3) | (-103, -32) (-85, -32) (-67, -32) |
| Illum R (×3) | (+67, -32) (+85, -32) (+103, -32) |
| Encoder L | (-30, -42) |
| Encoder R | (+30, -42) |
| Nav buttons (×3)| (-10, -42) (0, -42) (+10, -42) |
| Battery centre  | (0, -25)  (in bottom shell) |
| USB-C centre | (80, ?, on -Y wall) |

Sub-PCB mounting positions (TBD — depends on PCB outline) should mirror
the cluster centres.

Outer panel: **280 × 130 mm** (PANEL_W × PANEL_H).
Outer case: **286 × 136 mm**.
Available cavity inside top shell: ≈ 268 × 122 × 27 mm.

---

## 6. Cabling between PCBs

### 6.1 Sub-PCB to main PCB (×7)

5-wire JST-XH 2.5 mm: **3.3V, GND, SDA, SCL, /INT** (in that pin
order, matching nav3 ref board).

Length: 100-200 mm typical (long enough to route around the joysticks
and battery without strain).

Recommended connector on main PCB: 7 × JST-XH 5-pin vertical headers
(B5B-XH-A or compatible), laid out so each cable goes to its nearest
sub-PCB cluster. Each header is wired to one downstream channel of
the TCA9548A.

### 6.2 Joystick to main PCB (×2)

5-wire to a JST-PH 5 (or solder direct):
**3.3V, GND, X-pot wiper, Y-pot wiper, push-switch**.

Joysticks read directly via ESP32 ADC (NO I/O expander) for low latency
and full 12-bit resolution.

### 6.3 USB-C extension

Between USB-C panel-mount female (in bottom shell wall) and USB-C male
plug end → goes into a USB-C female receptacle on the main PCB. Just
one short pigtail; main PCB sees a standard USB-C signal.

### 6.4 Battery

- 2-pin XT30 male socket on main PCB ↔ XT30 female on battery leads,
  OR solder pads with screw terminal
- 3-pin JST-XH balance header on main PCB ↔ JST-XH on battery balance
  lead

### 6.5 Display

FFC ribbon (typically 18-wire for ST7796 + FT6236 combined), or 2
separate harnesses (display SPI + touch I2C). Length ≤ 50 mm to keep
SPI signal integrity.

### 6.6 Speaker

2 wires to solder pads on main PCB. Audio amp drives directly.

---

## 7. Power & charging

```
USB-C 5V/3A   ─→ IP5389 ─→ 2S charging  (8.4V max)
                    │
                    └─→ 5V boost output (for amp, optional)
                    
2S battery 7.4V ─→ Buck regulator ─→ 3.3V (ESP32, expanders, displays)
                                    
                  Direct 5V (boost) ─→ PAM8403 audio amp
```

Open: ESP32-S3 needs 3.3V; the WROOM-1 module includes its own LDO so
the input can be either 3.3V or 5V — pick the cleaner rail.

I²C pull-ups: 4.7 kΩ on SDA and SCL on the **main PCB only**, one
pair per downstream TCA9548A channel (so 8 pairs in total). Sub-PCBs
add nothing — the PCF8574A's internal weak pull-ups drive the switch
inputs but the bus pull-ups stay on the main side.

`/INT` lines from each sub-PCB also need a pull-up on the main PCB
(open-drain). 10 kΩ is fine.

---

## 8. Open questions / TBD

- Joystick exact pinout & mounting hole pitch — measure when in hand
- Toggle switch exact body dimensions — measure
- Illuminated button exact bushing thread (M12 vs M16) — measure
- Display module: confirm SPI vs parallel RGB; confirm FT6236 vs another
  touch IC
- Tact button spacing on `nav3` PCB: confirmed 10 mm (matches the case
  layout) — use the same `Button_Switch_THT:SW_PUSH_6mm_H5mm` footprint
  for consistency on toggle3 substitutes if needed
- Audio amp choice: PAM8403 (class-D, 3W stereo) vs simpler
- Speaker connector: solder pads vs JST
- ESP32 variant: S3 (native USB, more I/O) vs classic (cheaper, more
  mature) — recommendation: S3 for the USB story
- Counter-MOSFET / power-switch topology between battery and 3.3V
  regulator (soft-start, polarity protection)
- Whether to add a real-time clock (RTC) for telemetry timestamping
- SD card slot for log files? (separate header into main PCB)

---

## 9. Repository layout

```
hardware/transmitter/
├── parts/                       ← OpenSCAD vitamins + KiCad-exported PCBs
│   ├── battery.scad
│   ├── button_illuminated.scad
│   ├── button_tact.scad
│   ├── display.scad
│   ├── encoder.scad
│   ├── joystick.scad
│   ├── layout_front.scad        ← CENTRAL layout positions
│   ├── parameters.scad
│   ├── pcb_subpanel.scad        ← parametric placeholders + STL imports
│   ├── speaker.scad
│   ├── toggle_switch.scad
│   ├── usb_c_extension_cable.scad
│   ├── utils.scad
│   ├── nav3_actual.step         ← canonical KiCad STEP, tracked
│   ├── nav3_actual.stl          ← regenerated from STEP, gitignored
│   └── step_to_stl.py           ← FreeCAD headless conversion script
├── case/                        ← OpenSCAD case shell + printed parts
│   ├── parameters.scad
│   ├── top_shell.scad
│   ├── bottom_shell.scad
│   ├── battery_cover.scad
│   ├── battery_lid.scad
│   ├── nav_button_cap.scad
│   └── assembly_check.scad
├── pcb/                         ← KiCad projects, one folder per board
│   ├── nav3/                    ← reference template (see BOM.md)
│   │   ├── nav3.kicad_pro       ← project + board settings — copy to new boards
│   │   ├── nav3.kicad_sch       ← schematic (user-owned content)
│   │   ├── nav3.kicad_pcb       ← layout (user-owned)
│   │   ├── nav3_local.kicad_sym ← flattened symbols — copy + rename
│   │   ├── sym-lib-table        ← project-local lib registration — copy
│   │   └── BOM.md
│   ├── test/                    ← schematic sandbox for the remaining types
│   ├── toggle3/                 ← TODO
│   ├── illum3/                  ← TODO
│   ├── encoder1/                ← TODO
│   └── main/                    ← TODO
└── PCB_DESIGN_BRIEF.md          ← THIS FILE
```

When a board is finalised:
1. KiCad → `kicad-cli pcb export step <board>.kicad_pcb -o <board>.step`
2. Copy STEP → `parts/<board>_actual.step` (commit this)
3. `STEP_IN=parts/<board>_actual.step STL_OUT=parts/<board>_actual.stl
   freecadcmd parts/step_to_stl.py` (STL is gitignored — regenerate
   locally from the committed STEP)
4. Update `parts/pcb_subpanel.scad` to import the new STL (mirror the
   `subpanel_pcb_nav3()` pattern: `USE_REAL_PCB` toggle, `<NAME>_STL_OFFSET`
   computed from the KiCad board outline, `render(convexity=10) import(...)`
   wrap so F6 in OpenSCAD shows the imported geometry correctly)
5. Adjust the layout offset in `parts/layout_front.scad` if the KiCad
   board centroid doesn't match the panel cutout cluster centre (nav3
   needed a `-5` mm Y shift because switches sit "north" of centroid)

---

## 9.5 Workflow split (AI ↔ user)

> **Historical, 2026-08-07:** the tool-version claim below was recorded
> against kicad-mcp-pro v2.4.x and KiCad 9.0.7, both since superseded (see
> `.claude/skills/kicad-hardware/references/kicad-environment.md` for
> current versions). The scripted-layout-is-a-dead-end *conclusion* is not
> retested here; the division of labour it motivated still stands.

Empirical result from the nav3 board: scripted PCB layout was a dead
end (kicad-mcp-pro v2.4.x cannot reliably place + route on KiCad
9.0.7 from a clean schematic). The pragmatic division of labour is:

- **AI does**: schematic capture as a *starting template*, project
  scaffolding, design-rule files, BOM draft, STEP export + STL
  conversion + OpenSCAD case-fit verification.
- **User does**: schematic review and rework (the AI's draft is a
  starting point — pin assignments, decoupling, footprint choice, etc.
  may all need adjustment), and **the PCB layout in full**: footprint
  placement, routing, copper pours, silkscreen, mechanical keep-outs.
  Done in the KiCad GUI, not via scripts.

The AI hands off after `kicad-cli sch erc` is clean and a paper-tape
of nets + footprints exists. The user picks up there, owns the board
file from that point on, and emits a STEP when the layout is complete.
The AI then takes the STEP back into the OpenSCAD case-fit check.

## 9.6 Starting a new sub-PCB (template procedure)

`pcb/nav3/` is the canonical template — it carries the project and
board settings plus a flattened symbol library that transfer directly
to other sub-PCBs. To bootstrap a new board (e.g. `toggle3`):

```bash
cd hardware/transmitter/pcb
cp -r nav3 toggle3
cd toggle3
# Rename the project files
for f in nav3.*; do mv "$f" "${f/nav3/toggle3}"; done
mv nav3_local.kicad_sym toggle3_local.kicad_sym
# Substitute the string "nav3" → "toggle3" inside the project files
sed -i 's/nav3/toggle3/g' *.kicad_pro *.kicad_pcb sym-lib-table
# Rip out the nav3 schematic content (sheet contents, NOT the file
# header) so you start from an empty schematic with the same project
# settings, DRC rules, and symbol library
# (best done in the KiCad GUI: open the schematic, select all, delete)
# Drop the gitignored junk so it doesn't carry over
rm -rf nav3-backups output ~*.lck
```

Once the new project boots cleanly:

1. AI generates the schematic from the brief (parts list + nets).
2. Confirm KiCad can actually load the result — `kicad-cli sch erc`
   must not report "Failed to load schematic". If it does, see the
   file-format and `extends`-symbol gotchas in §9.7.
3. AI exports the schematic to PDF for user review.
4. **Hand off to user.** User reviews/reworks the schematic and does
   the entire PCB layout in the KiCad GUI.
5. After user-side DRC passes, AI runs `kicad-cli pcb export step` →
   `parts/<board>_actual.step` → `step_to_stl.py` → import into
   `pcb_subpanel.scad`.
6. Case-fit check via OpenSCAD assembly_check — tweak the
   `<NAME>_STL_OFFSET` and the `layout_front.scad` shift until the
   imported board's panel-side components line up with the case
   cutouts.

## 9.7 Gotchas inherited from nav3

> **Historical, 2026-08-07:** the entries below were recorded against
> kicad-mcp-pro v2.4.x and KiCad 9.0.7, both since superseded (see
> `.claude/skills/kicad-hardware/references/kicad-environment.md` for
> current versions). Re-tested on 2026-08-07: the `extends`-symbol failure
> and the file-format load failure no longer reproduce. Kept as history —
> confirm current behaviour before relying on it.

These bit us during nav3 and will bite again unless avoided:

**Net mapping bug**: kicad-mcp-pro v2.4.x assigns every PCB pad to
`+3V3` after a schematic-derived sync. Inspect the ratsnest before
trusting any scripted sync. This never fires for a fully GUI-driven
layout, which is the workflow §9.5 settles on.

**Schematic file format**: kicad-mcp-pro emits KiCad-10 (date stamp
20250316), KiCad 9.0.7 wants KiCad-9 (20240920), and it writes
`extends`-based symbols that KiCad 9 cannot load at all (PCF8574AT
extends PCF8574 → "Failed to load schematic"). The fix on nav3 was to
downgrade the version field and flatten the symbol into a standalone
copy in `<board>_local.kicad_sym`, which is why that library exists.

The scripts that performed both of these fixes have been deleted. They
had drifted to stale board dimensions (32 × 24 mm) and the pre-rework
I²C address (0x3F instead of 0x38), so re-running them would have
corrupted the finished layout. If the MCP path is picked up again,
write fresh ones against the board at hand — do not restore them from
git history.

**Reference designators must NOT start with `#`** (MCP skips those
when syncing footprints). Non-electrical decorations like OSHW logos
need a real-looking ref like `LOGO101`.

**STEP-to-STL gotcha**: KiCad's STEP export carries the PCB body, IC
bodies, connector body, etc. as separate solids that share faces.
OpenSCAD's CGAL backend (F6) rejects this as non-manifold and silently
drops geometry. `step_to_stl.py` already handles this by FreeCAD-fusing
all solids before tessellation, and `pcb_subpanel.scad` wraps the
import in `render()` as belt-and-braces. **Keep both.** If you change
the FreeCAD pipeline, run `admesh <board>_actual.stl` and confirm that
"Number of parts" stays in the single digits — high counts mean the
fuse failed.

**KiCad screen-Y vs STEP-Y**: KiCad PCB editor uses screen-style Y
(positive = down), STEP/STL use right-handed Y (positive = up). The
`<NAME>_STL_OFFSET` in `pcb_subpanel.scad` corrects for this; if a
new board appears mirrored after import, double-check the sign of
the Y components in the offset.

**Switch / connector centroid != PCB centroid**: nav3's switches are
5 mm "north" of the PCB centre because the connector takes the bottom
edge. The fix lives in `parts/layout_front.scad` (`translate([0,
NAV_BTN_Y - 5, SUBPCB_Z_NAV])`). Each new sub-PCB will need its own
offset measured once and hard-coded.

**Outline grew from estimate**: nav3 ended up at 32 × 30 mm vs the
original 32 × 16 mm guess. The driver was the SOIC-16W IC body on
B.Cu plus 4 corner mounts plus the JST-XH 5-pin connector. Plan for
similar growth on the other sub-PCBs — the design brief estimates
are minimums, not hard limits.

---

## 10. Constraints from the case

- Top shell internal cavity: 268 × 122 × 27 mm (W × D × H above panel
  interior, with taper toward 280 × 130 at mating rim)
- Case-corner bosses at (±129, ±56) — ~6 mm OD pillars from panel to
  mating rim with stiffener fins, do NOT route PCBs into these corners
- 4 toggle bushings + 6 illum buttons + 2 encoder bushings + 3 nav
  buttons + 2 joystick mounting plates eat into the top-shell cavity
- Battery occupies (0, -25) in the bottom shell, 80 × 35 × 15 mm + 1 mm
  wall clearance
- USB-C adapter at (80, on -Y wall) — sub-PCBs near this corner must
  leave clearance for the cable bend radius

If a sub-PCB collides with a case feature, the case takes precedence —
the sub-PCB has to shrink or move, since the panel cutouts are fixed by
ergonomics.

---

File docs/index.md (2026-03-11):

---
layout: default
title: OpenDriveHub
---

# OpenDriveHub

**Open-source modular control platform for functional model vehicles**  
Excavators · Dump trucks · Tractors · Ground-based RC models





---

## What is OpenDriveHub?

OpenDriveHub is a hobby-grade RC transmitter and receiver platform designed
specifically for **functional model vehicles** – not aircraft.  It focuses on
modularity, simplicity, and always-on telemetry.

The firmware is written in **modern C++20** with a unified `odh::` namespace,
`enum class` types, `constexpr` configuration, and shared libraries.

---

## Key Features

| Feature | Details |
|---|---|
| **Modular transmitter** | Plug-in front slots for switches, buttons, potentiometers, encoders |
| **I²C backplane** | TCA9548A mux – identical I²C devices in every slot, no address conflicts |
| **Bidirectional telemetry** | Battery voltage, RSSI, link state, and custom sensor values – always active |
| **ESP-NOW radio link** | No router or WiFi infrastructure needed; low latency |
| **ILI9341 touch-screen display** | 320×240 colour LCD with XPT2046 resistive touch; LVGL widget UI |
| **PCA9685 servo driver** | I²C-based 16-channel PWM output on the receiver |
| **Receiver-initiated discovery** | Receivers announce their presence; operator selects a vehicle on the touch screen |
| **Vehicle model presets** | Built-in function maps for Generic, Dump Truck, Excavator, Tractor, and Crane |
| **FreeRTOS firmware** | Dedicated tasks for control (50 Hz), display (4 Hz), and web config |
| **Always-on web configuration** | WiFi AP + REST API (ESPAsyncWebServer + ArduinoJson v7) starts automatically at boot on both TX and RX; settings stored in ESP32 NVS |
| **Linux simulation** | Full TX + RX simulation on a PC – SDL2 display window, keyboard channel control, UDP radio loopback; no hardware needed |
| **Modern C++20** | Unified `odh::` namespace, `enum class`, `constexpr`, `std::optional`, shared libraries |
| **Open hardware** | Standard, widely available components; no proprietary chips |
| **GPL-3.0** | Fully open firmware and hardware under GPL-3.0 |

---

## System Architecture

```
┌──────────────────────────────────┐       ESP-NOW        ┌────────────────────────┐
│         TRANSMITTER              │◄────────────────────►│      RECEIVER          │
│  ┌─────────────────────────┐     │    Control @ 50 Hz   │                        │
│  │ ESP32 (FreeRTOS)        │     │   Telemetry @ 10 Hz  │  ESP32 (FreeRTOS)      │
│  │  taskControl  (core 1)  │     │                      │  taskOutput  (core 1)  │
│  │  taskDisplay  (core 0)  │     │                      │  taskTelemetry (core 0)│
│  │  taskWebConfig (core 0) │     │                      │                        │
│  └─────────────────────────┘     │                      │  PCA9685 PWM outputs   │
│  ┌──────────────────────────┐    │                      │  Battery monitor       │
│  │ TCA9548A I²C Mux         │    │                      │  Failsafe on link loss │
│  │  Slot 0 … Slot 5         │    │                      └────────────────────────┘
│  │  [SW][BTN][POT][ENC][ ][ ]│   │
│  └──────────────────────────┘    │
│  SPI LCD (ILI9341 + XPT2046 touch, LVGL)  │
│  Battery ADC                              │
└──────────────────────────────────────────────┘
```

---

## Module Types

| Module | I²C Device | Channels | Application |
|---|---|---|---|
| **Switch** | PCF8574 @ 0x20 | 8 | Toggle switches for lights, attachments |
| **Button** | PCF8574 @ 0x21 | 8 | Momentary buttons for horn, reset, etc. |
| **Potentiometer** | ADS1115 @ 0x48 | 4 | Joystick axes, throttle levers, trim knobs |
| **Encoder** | AS5600 @ 0x36 | 1 | Absolute rotary knobs |

Modules are detected automatically at boot.  No configuration is needed – just
plug in and power on.

---

## Hardware

The transmitter and receiver are built from **standard, widely available components**:

- ESP32-DevKitC development board
- TCA9548A I²C multiplexer breakout
- ILI9341 320×240 SPI LCD with XPT2046 resistive touch (transmitter only)
- PCA9685 16-channel PWM driver (receiver only)
- PCF8574 GPIO expanders (switch/button modules)
- ADS1115 ADC (potentiometer module)
- AS5600 magnetic encoder (encoder module)

Full BOMs and wiring diagrams:
- [Transmitter Hardware](hardware/transmitter/)
- [Receiver Hardware](hardware/receiver/)
- [Switch Module](hardware/modules/switch/)
- [Button Module](hardware/modules/button/)
- [Potentiometer Module](hardware/modules/potentiometer/)
- [Encoder Module](hardware/modules/encoder/)

---

## Getting Started

### Prerequisites

- [PlatformIO](https://platformio.org/) (VS Code plugin or CLI)
- ESP32 development board (× 2: one for transmitter, one for receiver)

### Quick start

```bash
git clone https://github.com/peterus/OpenDriveHub.git
cd OpenDriveHub/firmware

# Flash transmitter
pio run -e transmitter -t upload

# Flash receiver
pio run -e receiver -t upload

# Run host-side unit tests (90 tests)
pio test -e native
```

### Run the simulation (no hardware needed)

```bash
cd firmware

# Terminal 1 – receiver
pio run -e sim_rx -t exec

# Terminal 2 – transmitter (headless terminal simulation)
pio run -e sim_tx -t exec
```

See the **[Simulation Guide](https://github.com/peterus/OpenDriveHub/blob/main/firmware/sim/README.md)** for full details.

See **[Getting Started Guide](getting-started)** for full step-by-step instructions.

---

## Radio Protocol

OpenDriveHub uses a simple, compact binary protocol over ESP-NOW.
All types live in `namespace odh` (defined in `firmware/lib/odh-protocol/Protocol.h`):

| Direction | Packet | Rate | Size |
|---|---|---|---|
| TX → RX | `odh::ControlPacket` | 50 Hz | 73 bytes |
| RX → TX | `odh::TelemetryPacket` | 10 Hz | 30 bytes |
| TX → RX | `odh::BindPacket` | once | 11 bytes |
| RX → broadcast | `odh::AnnouncePacket` | 2 Hz | 28 bytes |
| TX → RX | Disconnect (`odh::BindPacket` with type 0x40) | once | 11 bytes |

All packets use an XOR checksum.  See the [Protocol Reference](protocol) for details.

---

## Documentation

- [Getting Started](getting-started)
- [System Architecture](architecture)
- [Backplane & Modules](backplane)
- [Protocol Reference](protocol)
- [Simulation Guide](https://github.com/peterus/OpenDriveHub/blob/main/firmware/sim/README.md)

---

## License

OpenDriveHub is released under the **GNU General Public License v3.0**.  
You are free to use, modify, and distribute this project under the terms of that licence.

[View on GitHub](https://github.com/peterus/OpenDriveHub) ·
[Report an Issue](https://github.com/peterus/OpenDriveHub/issues) ·
[GPL-3.0 Licence](https://github.com/peterus/OpenDriveHub/blob/main/LICENSE)

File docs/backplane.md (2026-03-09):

# Backplane

The OpenDriveHub backplane is an **I²C multiplexer bus** that connects
plug-in input modules to the transmitter.  It is built around a
**TCA9548A** 8-channel I²C switch.

---

## How It Works

The TCA9548A sits on the ESP32's main I²C bus (SDA = GPIO21, SCL = GPIO22)
at address **0x70** (configurable in `odh::config::tx::kI2cMuxAddr`).

Each module is connected to one of the mux's eight downstream channel pairs
(SD0/SC0 through SD7/SC7).  Because only one channel is active at a time,
modules on different slots may use the same I²C address without conflict.

```
ESP32 (SDA, SCL)
   │
   └── TCA9548A  (0x70)
         ├── CH0 → Slot 0 module (e.g. PotModule at 0x48)
         ├── CH1 → Slot 1 module (e.g. SwitchModule at 0x20)
         ├── CH2 → Slot 2 module …
         ├── CH3 → (empty)
         ├── CH4 → …
         ├── CH5 → …
         ├── CH6 → (not populated)
         └── CH7 → (not populated)
```

The default slot count is **6** (`odh::config::tx::kModuleSlotCount`).
This is a software limit; the hardware supports up to 8.

---

## Firmware Interface

The backplane is managed by the **`odh::Backplane`** class
(`firmware/src/transmitter/backplane/Backplane.h`).

### Key API

```cpp
namespace odh {

class Backplane {
public:
    explicit Backplane(uint8_t muxAddress = 0x70, uint8_t slotCount = 8);

    bool begin();                   // Initialise and verify TCA9548A
    bool selectSlot(uint8_t slot);  // Activate one channel
    void deselectAll();             // Deactivate all channels
    uint8_t activeSlot() const;     // Current active slot (kNoSlot if none)
    uint8_t scanSlots(uint8_t addr);// Probe each slot for a device
    uint8_t slotCount() const;
    bool isReady() const;
};

} // namespace odh
```

### Usage Pattern

```cpp
odh::Backplane bp(odh::config::tx::kI2cMuxAddr, odh::config::tx::kModuleSlotCount);
bp.begin();

for (uint8_t i = 0; i < bp.slotCount(); i++) {
    bp.selectSlot(i);
    // probe / read from whatever device is on this channel
}
bp.deselectAll();
```

---

## Module Detection

The **`ModuleManager`** uses `Backplane::selectSlot()` to iterate over each
slot and probes a fixed set of I²C addresses to identify the module type:

| Probe Address | Chip | Module Type | Class |
|---|---|---|---|
| 0x48 | ADS1115 | `ModuleType::Potentiometer` | `PotModule` |
| 0x20 | PCF8574 | `ModuleType::Switch` | `SwitchModule` |
| 0x21 | PCF8574 | `ModuleType::Button` | `ButtonModule` |
| 0x36 | AS5600 | `ModuleType::Encoder` | `EncoderModule` |

If no known device responds at any of the probed addresses, the slot is
marked empty.  Detection runs once at startup.

The module type enum is defined in `firmware/src/transmitter/modules/IModule.h`:

```cpp
enum class ModuleType : uint8_t {
    Unknown       = 0x00,
    Switch        = 0x01,
    Button        = 0x02,
    Potentiometer = 0x03,
    Encoder       = 0x04,
};
```

---

## Adding a New Module Type

1. **Create the header and source** in `firmware/src/transmitter/modules/`:

   ```cpp
   // MyModule.h
   #pragma once
   #include "IModule.h"

   namespace odh {

   class MyModule : public IModule {
   public:
       explicit MyModule(uint8_t slot);
       bool begin() override;
       void update() override;
       uint8_t inputCount() const override;
       uint16_t inputValue(uint8_t index) const override;
   };

   } // namespace odh
   ```

2. **Add a new enum value** to `ModuleType`:

   ```cpp
   enum class ModuleType : uint8_t {
       // ... existing types ...
       MyDevice = 0x05,
   };
   ```

3. **Register the probe** in `ModuleManager` – add your I²C address and
   instantiation logic to the detection loop.

4. **Design the hardware module** – create a directory under
   `hardware/modules/your_module/` with a `README.md` describing:
   - Chip / breakout board used
   - I²C address (must not conflict with existing modules)
   - Schematic / wiring table
   - BOM

---

## Hardware Notes

### I²C Pull-ups

The TCA9548A requires pull-up resistors on the **upstream** bus (ESP32 side):
- 4.7 kΩ from 3V3 to SDA
- 4.7 kΩ from 3V3 to SCL

Module breakout boards (ADS1115, PCF8574, AS5600) typically include their
own pull-ups on the downstream side.  If using a bare chip, add 4.7 kΩ
pull-ups on each downstream channel pair as well.

### Clock Speed

The bus runs at **400 kHz** fast-mode (`odh::config::kI2cFreqHz`).  All
currently supported chips handle this speed.

### Power

All modules and the mux are powered from the transmitter's 3.3 V rail.
Current draw per slot is typically < 5 mA, but analog modules with
potentiometers connected to 3.3 V may draw more through the wiper.

---

## Slot Connector

See `hardware/transmitter/README.md` for the physical connector pinout.
Each slot header exposes:

| Pin | Signal |
|-----|---|
| 1 | 3V3 |
| 2 | GND |
| 3 | SDAn (TCA9548A channel N) |
| 4 | SCLn (TCA9548A channel N) |

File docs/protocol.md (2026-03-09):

# Protocol Specification

This document describes the radio protocol used between the OpenDriveHub
transmitter and receiver.

**Source file:** `firmware/lib/odh-protocol/Protocol.h`
**Function map:** `firmware/lib/odh-protocol/FunctionMap.h`

---

## Overview

OpenDriveHub uses **ESP-NOW** as the radio transport.  ESP-NOW operates on a
single WiFi channel (default: channel 1, configurable in
`odh::config::kRadioWifiChannel`) and delivers frames of up to 250 bytes with
no connection setup.

All OpenDriveHub packets share a common 6-byte header followed by a
payload and exactly one checksum byte at the end.

---

## Common Header

```
Offset  Size  Field         Value / Description
──────  ────  ────────────  ──────────────────────────────
0       1     magic[0]      0x4F ('O')
1       1     magic[1]      0x44 ('D')
2       1     version       odh::kProtocolVersion (currently 1)
3       1     type          odh::PacketType enum value
4       2     sequence      Little-endian packet counter
```

The **last byte** of every packet is an XOR checksum of all preceding bytes,
computed by `odh::checksum()`.

---

## Packet Types

```cpp
enum class PacketType : uint8_t {
    Control    = 0x01,  // TX → RX
    Telemetry  = 0x02,  // RX → TX
    Bind       = 0x10,  // TX → RX (connect)
    Ack        = 0x20,  // General acknowledgement
    Announce   = 0x30,  // RX → broadcast (discovery)
    Disconnect = 0x40,  // TX → RX (release link)
};
```

---

## ControlPacket (73 bytes)

Sent by the transmitter at **50 Hz**.  Contains the current function values
and trim offsets for up to 16 functions.

```
Offset  Size  Field                    Description
──────  ────  ───────────────────────  ─────────────────────────────────
0–5     6     header                   Common header (type = 0x01)
6       1     function_count           Number of active FunctionValue entries (≤ 16)
7–70    64    functions[16]            Array of FunctionValue structs (4 bytes each)
71      1     flags                    Reserved
72      1     checksum                 XOR over bytes 0–71
```

### FunctionValue (4 bytes, packed)

```
Offset  Size  Field      Description
──────  ────  ─────────  ──────────────────────────────────────────
0       1     function   odh::Function enum value (0x00–0x0F, 0xFF = None)
1       2     value      RC pulse width in µs [1000, 2000], LE
3       1     trim       Signed trim offset (±100)
```

Each function represents a logical vehicle control (drive, steering, boom,
etc.) rather than a raw channel number.

---

## TelemetryPacket (30 bytes)

Sent by the receiver at **10 Hz** while connected.

```
Offset  Size  Field            Description
──────  ────  ───────────────  ─────────────────────────────────
0–5     6     header           Common header (type = 0x02)
6       2     battery_mv       Battery voltage in mV, LE
8       1     rssi             Receiver RSSI (dBm, signed)
9       1     link_state       odh::LinkState enum value
10      1     model_type       odh::ModelType enum value
11      1     model_flags      Reserved flags
12      1     sensor_count     Number of sensor values (≤ 8)
13–28   16    sensors[8]       16-bit sensor values, LE
29      1     checksum         XOR over bytes 0–28
```

---

## BindPacket (11 bytes)

Sent by the transmitter to initiate a link, or to disconnect.

```
Offset  Size  Field      Description
──────  ────  ─────────  ──────────────────────────────────
0–5     6     header     Common header (type = 0x10 or 0x40)
6       6     mac        Source device MAC address
10      1     checksum   XOR over bytes 0–9
```

---

## AnnouncePacket (28 bytes)

Broadcast by the receiver when in **Disconnected** state.  The transmitter
listens for these packets to discover available vehicles.

```
Offset  Size  Field         Description
──────  ────  ────────────  ──────────────────────────────────
0–5     6     header        Common header (type = 0x30)
6       6     mac           Receiver MAC address
12      1     model_type    odh::ModelType enum value
13      16    name          Vehicle name (null-terminated, max 16 chars)
27      1     checksum      XOR over bytes 0–26
```

---

## Connection Flow

```
Receiver                        Transmitter
────────                        ───────────
   │                                 │
   │ ◄── [power on] ──►             │
   │                                 │
   ├─── AnnouncePacket (broadcast) ──────►│  (every 500 ms)
   ├─── AnnouncePacket ─────────────────►│
   │                                 │
   │   (user taps vehicle on LCD)    │
   │                                 │
   │◄──────── BindPacket ───────────┤  (type = 0x10)
   │                                 │
   │  [state → Connected]           │  [state → Connected]
   │                                 │
   ├─── TelemetryPacket ───────────►│  (10 Hz)
   │◄──────── ControlPacket ────────┤  (50 Hz)
   │                                 │
   │   (user taps Disconnect)       │
   │                                 │
   │◄──────── BindPacket ───────────┤  (type = 0x40)
   │                                 │
   │  [state → Disconnected]        │  [state → Scanning]
   │                                 │
   ├─── AnnouncePacket (broadcast) ──────►│  (resumes)
```

---

## Failsafe

If the receiver does not receive a `ControlPacket` within
`odh::config::kRadioFailsafeTimeoutMs` (default 500 ms), it enters
**Failsafe** state.

In Failsafe:
- All function outputs are set to `odh::config::kFailsafeChannelValue`
  (default 1500 µs = center).
- The receiver continues sending `TelemetryPacket` with
  `link_state = LinkState::Failsafe`.
- If the link is lost for longer than `odh::config::kRadioLinkTimeoutMs`
  (default 3000 ms), the receiver transitions back to **Disconnected** and
  resumes broadcasting `AnnouncePacket`.

---

## Enumerations

### ModelType

```cpp
enum class ModelType : uint8_t {
    Generic   = 0x00,
    DumpTruck = 0x01,
    Excavator = 0x02,
    Tractor   = 0x03,
    Crane     = 0x04,
};
```

### Function

```cpp
enum class Function : uint8_t {
    Drive    = 0x00,  Steering = 0x01,
    Aux1     = 0x02,  Aux2     = 0x03,
    Aux3     = 0x04,  Aux4     = 0x05,
    BoomUD   = 0x06,  BoomLR   = 0x07,
    Bucket   = 0x08,  Swing    = 0x09,
    DumpBed  = 0x0A,  Pto      = 0x0B,
    Hitch    = 0x0C,  Winch    = 0x0D,
    TrackL   = 0x0E,  TrackR   = 0x0F,
    None     = 0xFF,
};
```

### LinkState

```cpp
enum class LinkState : uint8_t {
    Disconnected = 0,
    Binding      = 1,
    Connected    = 2,
    Failsafe     = 3,
    Scanning     = 4,
};
```

---

## Function Map

`firmware/lib/odh-protocol/FunctionMap.h` provides:

- `odh::functionName(Function)` – human-readable label (e.g. `"Boom U/D"`)
- `odh::modelName(ModelType)` – human-readable model label (e.g. `"Excavator"`)
- `odh::defaultFunctionMap(ModelType)` – returns a `FunctionMapping` struct
  with the default set of functions for the given model type
- `odh::functionToChannel()` / `odh::channelToFunction()` – lookup helpers
  between function enums and output channel indices

### Default Mappings

| Model | Functions |
|---|---|
| Generic | Drive(0), Steering(1), Aux1(2), Aux2(3), Aux3(4), Aux4(5) |
| DumpTruck | Drive(0), Steering(1), DumpBed(2) |
| Excavator | TrackL(0), TrackR(1), BoomUD(2), BoomLR(3), Bucket(4), Swing(5) |
| Tractor | Drive(0), Steering(1), Pto(2), Hitch(3) |
| Crane | Drive(0), Steering(1), BoomUD(2), Winch(3), Swing(4) |

---

## Constants

| Constant | Namespace | Value |
|---|---|---|
| `kMagic0` | `odh::` | `0x4F` ('O') |
| `kMagic1` | `odh::` | `0x44` ('D') |
| `kProtocolVersion` | `odh::` | `1` |
| `kMaxChannels` | `odh::` | `16` |
| `kMaxFunctions` | `odh::` | `16` |
| `kMaxSensors` | `odh::` | `8` |
| `kMaxDiscovered` | `odh::` | `8` |
| `kVehicleNameMax` | `odh::` | `16` |
| `kChannelMin` | `odh::` | `1000` µs |
| `kChannelMid` | `odh::` | `1500` µs |
| `kChannelMax` | `odh::` | `2000` µs |

---

## Legacy Compatibility

`Protocol.h` provides type aliases and constant mappings for older code that
still uses the `OdhControlPacket_t`, `ODH_PKT_*`, `ODH_FUNC_*` naming
convention.  These are defined **outside** the `odh` namespace and will be
removed in a future version.

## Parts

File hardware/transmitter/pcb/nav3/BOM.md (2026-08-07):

# nav3 — Bill of Materials

3-button I²C navigation sub-PCB. PCF8574A reads 3 momentary tact switches and reports state to the main MCU over I²C, with a hardware interrupt line so the host can sleep until input changes.

I²C address: **0x38** (A0=A1=A2 → GND, hard-wired). The transmitter has two separate I²C buses; this PCB sits on the sub-PCB bus, isolated from the FT6236 touch controller (which lives on the display bus, also at 0x38). No conflict.

Pull-ups (4.7 kΩ on SDA/SCL) live on the **main PCB**, not here — exactly once per sub-PCB bus.
PCF8574A internal pull-ups (~100 µA quasi-bidirectional) drive the switch inputs to VCC at rest; pressing the switch pulls the GPIO to GND. The /INT pin is open-drain — needs a pull-up on the main PCB too.

## Parts

| Ref | Qty | Value | KiCad Symbol | KiCad Footprint | Source | Notes |
|-----|-----|---|---|---|---|---|
| U101 | 1 | PCF8574AT | `nav3_local:PCF8574AT` | `Package_SO:SOIC-16W_7.5x10.3mm_P1.27mm` | project-local sym | I²C 8-bit I/O expander. Kept as a flattened (non-`extends`) copy in the project-local library so it loads standalone |
| SW101, SW102, SW103 | 3 | TS-A6PV-130 / equiv | `Switch:SW_Push` | `Button_Switch_THT:SW_PUSH_6mm_H5mm` | std lib | 6×6 mm THT tact, 5 mm body height, 4-pin |
| H101, H102, H103, H104 | 4 | MountingHole | `Mechanical:MountingHole` | `MountingHole:MountingHole_2.2mm_M2` | std lib | 4-corner mount to case (M2 screws) |
| C101 | 1 | 100 nF | `Device:C` | `Capacitor_SMD:C_0805_2012Metric` | std lib | Decoupling on U1 VCC, X7R, 0805 chosen for hand-soldering |
| J101 | 1 | B5B-XH-A | `Connector_Generic:Conn_01x05` | `Connector_JST:JST_XH_B5B-XH-A_1x05_P2.50mm_Vertical` | std lib | JST-XH 5-pin (3V3, GND, SDA, SCL, INT), white locking crimp connector |
| LOGO101, LOGO102 | 2 | OSHW logo | `Graphic:Logo_Open_Hardware_Small` | `Symbol:OSHW-Logo_5.7x6mm_SilkScreen` | std lib | Silkscreen-only OSHW logo on F.Cu (LOGO101) and B.Cu mirrored (LOGO102, rot=180). Reference must NOT start with `#` or PCB sync skips it |

Total: **12 footprints** (10 BOM-relevant + 2 silk-only graphics), all from KiCad standard libraries — no project-local footprint libs needed.

## Net list

| U101 pin | Net | Connection |
|---|-----|---|
| 1 (A0) | GND | Tied to GND → address bit 0 = 0 |
| 2 (A1) | GND | Tied to GND → address bit 1 = 0 |
| 3 (A2) | GND | Tied to GND → address bit 2 = 0 |
| 4 (P0) | NAV_LEFT | SW101.1 → GND when pressed |
| 5 (P1) | NAV_MID | SW102.1 → GND when pressed |
| 6 (P2) | NAV_RIGHT | SW103.1 → GND when pressed |
| 7 (P3) | — | NC (free GPIO, leave NC) |
| 8 (VSS) | GND | + C101 −, J101 pin 2 |
| 9 (P4) | — | NC |
| 10 (P5) | — | NC |
| 11 (P6) | — | NC |
| 12 (P7) | — | NC |
| 13 (/INT) | IO_INT | J101 pin 5 — open-drain, MCU watches for input changes (no polling) |
| 14 (SCL) | I2C_SCL | J101 pin 4 |
| 15 (SDA) | I2C_SDA | J101 pin 3 |
| 16 (VDD) | 3V3 | + C101 +, J101 pin 1 |

| J101 pin | Net |
|---|-----|
| 1 | 3V3 |
| 2 | GND |
| 3 | I2C_SDA |
| 4 | I2C_SCL |
| 5 | IO_INT |

## Mechanical envelope

- Board outline: **32 × 30 mm** (matches updated `NAV_PCB_SIZE` in `hardware/transmitter/parts/pcb_subpanel.scad`)
- F.Cu (panel side): **only** SW101/SW102/SW103 (and one OSHW logo)
- B.Cu (case-interior side): U101, C101, J101, second OSHW logo
- B.Cu carries a solid GND copper pour covering the full board
- Mount holes 3 mm inset from each corner (4× M2)
- J101 vertical THT exits toward the case interior; cable is 5-wire JST-XH

## Source references

- Design brief: `hardware/transmitter/PCB_DESIGN_BRIEF.md` §3 (PCB list), §4.5 (tact buttons)
- Panel layout: `hardware/transmitter/parts/layout_front.scad` `NAV_BTN_*` constants
- Sub-PCB OpenSCAD model: `hardware/transmitter/parts/pcb_subpanel.scad`
- Tact switch model: `hardware/transmitter/parts/button_tact.scad`

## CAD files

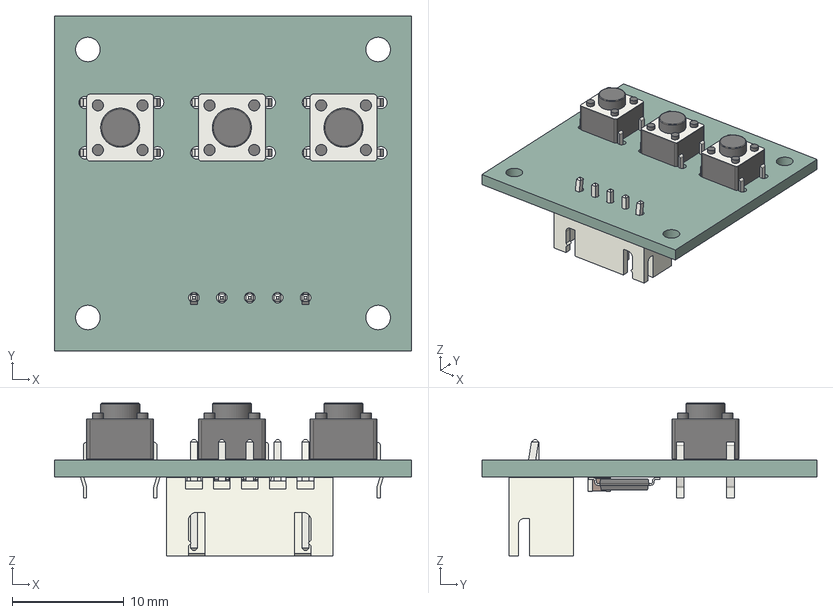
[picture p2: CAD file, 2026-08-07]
hardware/transmitter/parts/nav3_actual.step
32.0 x 30.0 x 13.7 mm
SW_PUSH_6mm_H5mm x 3
C_0805_2012Metric
TSSOP-16_4.4x5mm_P0.65mm
JST_XH_B5B-XH-A_1x05_P2.50mm_Vertical
nav3_copper
nav3_PCB

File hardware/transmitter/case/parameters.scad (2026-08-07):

// Case-specific constants for the transmitter shell.
//
// Coordinate convention used by all case modules:
//   z = 0   : panel-mating face (= panel inner surface, where component
//             bodies meet the panel from inside the case)
//   z = +Z  : out toward the user (panel material occupies z=[0, PANEL_T])
//   z = -Z  : into the case interior (component bodies live here)
//   x = 0   : panel horizontal center (matches layout_front.scad)
//   y = 0   : panel vertical center (+Y up, -Y down)

include <BOSL2/std.scad>
include <../parts/parameters.scad>   // global $fn, FIT_*, INSERT_M3_*
include <../parts/utils.scad>        // COLOR_*, helpers

// ----- Front-panel reference (must match parts/layout_front.scad) -----
PANEL_W = 280;
PANEL_H = 130;

// ----- Wall and panel thickness -----
WALL_T          = 3;     // outer side-wall thickness
PANEL_T         = 3;     // front-panel thickness (where components mount)

// ----- Top vs bottom shell depth (sum = total case interior depth) -----
// TOP_DEPTH must clear the joystick body (28mm) + pin block (6mm) — pin
// block is allowed to extend a few mm into the bottom shell cavity since
// nothing else lives at that XY position.
// BOTTOM_DEPTH must clear the battery + slot walls + lid (~18mm) plus a
// little headroom.
TOP_DEPTH       = 30;    // top shell rear opening to front panel face
BOTTOM_DEPTH    = 25;    // bottom shell rear face to front opening

// ----- Outer cosmetics -----
// CORNER_R and TOP_EDGE_R should match (or be close) so the vertical
// rounding and the top-face rounding blend smoothly at the corner. Big
// difference between them creates a visible "saddle" seam at the
// front-top corners.
CORNER_R        = 14;    // vertical corner rounding
TOP_EDGE_R      = 2.5;   // top-face edge rounding (must stay below WALL_T=3
                         // or it eats through the panel slab at the corners)
EDGE_FILLET     = 1.5;   // small fillet on inner edges to reduce stress

// ----- Taper: front face bigger than back face for a "shaped" profile -----
// size1 (back) = front dimension - 2*TAPER_*
TAPER_X         = 6;     // case narrows by 12mm total in X from front to back
TAPER_Y         = 4;     // case narrows by 8mm total in Y from front to back

// ----- Outer dimensions (without grips) -----
CASE_W          = PANEL_W + 2*WALL_T;
CASE_H          = PANEL_H + 2*WALL_T;
CASE_DEPTH      = TOP_DEPTH + BOTTOM_DEPTH;

// ----- Mounting bosses for top-bottom screw fastening (M3 + heat-set) -----
BOSS_OD         = 7;
BOSS_INSERT_D   = INSERT_M3_POCKET_D;
BOSS_INSERT_H   = INSERT_M3_POCKET_H;

// 4 case-corner bosses connect top and bottom shells. Insert lives in the
// top-shell boss; screw enters from the back panel exterior, runs through
// a hollow bottom-shell boss, crosses the mating face, threads into the
// insert. Position chosen so the boss merges into the side wall at the
// panel face (smallest section due to taper) for strength while staying
// fully inside the cavity at the mating face.
//
// The top boss is kept short to clear the toggle-switch bodies that hang
// under the front panel into the upper case. The bottom boss runs the
// full bottom-shell depth so the screw is supported all the way.
//
// Screw: M3 x 40 (5mm thread engagement into the insert).
CASE_BOSS_OFFSET_X   = 129;
CASE_BOSS_OFFSET_Y   = 56;
CASE_BOSS_HEIGHT_TOP = TOP_DEPTH - PANEL_T;       // full pillar — anchors at panel
CASE_BOSS_HEIGHT_BOT = BOTTOM_DEPTH - PANEL_T;    // full pillar — anchors at back panel
// Conical foot at the bottom-shell boss base. Widens the moment of inertia
// at the cantilever root so the tower doesn't snap off under lateral load.
CASE_BOSS_FOOT_D     = 10;
CASE_BOSS_FOOT_H     = 4;

// Stiffener fins from boss to the two nearest walls. Two per boss
// (cardinal directions toward the case corner), full boss height. The
// fin is intentionally OVERLENGTH — the shell trims it to the outer
// prismoid via intersection, so the outer face follows the wall taper
// and the rounded corner exactly at every Z level.
CASE_BOSS_FIN_L      = 20;     // overlength, will be clipped to outer wall
CASE_BOSS_FIN_T      = 1.5;

// ----- Battery compartment (LiPo cover access on the bottom-shell back) -----
// Battery is BATT_BODY=[80,35,15]; cover/opening sized with clearance.
// Position is in case-world XY; battery shifted toward the bottom of the
// case for grip-balance (heavier mass closer to the user's grip).
BATT_POS_X        = 0;
BATT_POS_Y        = -25;
BATT_OPENING_W    = 82;     // through-hole for battery insertion (battery + 1mm/side)
BATT_OPENING_H    = 37;
BATT_COVER_W      = 110;    // cover plate footprint (must be wider than the boss row)
BATT_COVER_H      = 64;
BATT_COVER_T      = 2;      // cover plate thickness
BATT_COVER_RECESS = 2;      // nominal recess depth — actual cut = RECESS + Z_GAP,
                            // so the cover top sits BATT_COVER_Z_GAP below flush
BATT_COVER_R      = 2;      // corner rounding on the cover plate
// Print clearance so the cover doesn't bind in the recess and the gap is
// visible in OpenSCAD assembly checks.
BATT_COVER_FIT    = FIT_FREE; // XY clearance per side (slip fit)
BATT_COVER_Z_GAP  = 0.3;      // Z gap — cover top this far below outer panel face

// Corner bosses inside the bottom-shell — each holds two M3 heat-set inserts
// (one near the back-panel for the exterior cover, one at the top for the
// interior battery lid). Boss XY positions clear the battery body with
// ~5mm to each side. Cover screws inset 5mm from cover edge match these.
BATT_BOSS_OD       = 7;     // 1.5mm wall around M3 insert pocket
BATT_BOSS_OFFSET_X = 45;    // = BATT_BODY.x/2 + 5 (battery edge + 5mm)
BATT_BOSS_OFFSET_Y = 22;    // = BATT_BODY.y/2 + 4.5
BATT_BOSS_HEIGHT   = 16;    // boss reaches from back-panel-interior to lid level

// Battery-slot walls — 4 walls between the bosses keep the LiPo from
// sliding around. The +Y wall has a notch where the power + balance
// wires exit toward the main PCB.
BATT_WALL_T        = 2;     // slot wall thickness
BATT_WALL_INSET    = 1;     // gap between battery edge and wall inner face
BATT_WIRE_NOTCH_W  = 22;    // notch width in +Y wall (X axis)
BATT_WIRE_NOTCH_H  = 10;    // notch height (Z axis), measured from boss top down

// Interior battery lid — sits on the boss tops, prevents the LiPo from
// dropping into the case interior.
BATT_LID_W        = BATT_COVER_W;
BATT_LID_H        = BATT_COVER_H;
BATT_LID_T        = 2;
BATT_LID_R        = BATT_COVER_R;

// M3 clearance hole for the screws (slightly oversized for FDM tolerance).
COVER_SCREW_CLEAR = 3.5;

// ----- USB-C extension cable mount (parts/usb_c_extension_cable.scad) -----
// Female panel-mount adapter sits INSIDE the case, flange flush against
// the inner -Y wall surface. The adapter's flange has built-in M2 threads;
// 2 M2 screws come from outside through wall clearance holes and thread
// into the adapter, clamping it against the inner wall.
//
// The middle wall cutout has to be big enough for the USB-C plug AND its
// over-moulded plastic boot — heavy-duty cables can have 12-14mm boots.
USBC_POS_X          = 80;       // X centre on the -Y wall
USBC_POS_Z          = -11;      // Z in BOTTOM-SHELL LOCAL coords (centre of cavity)
USBC_SCREW_PITCH    = 17;       // confirmed
USBC_SCREW_CLEAR    = 2.4;      // M2 clearance through wall
USBC_PLUG_CLEAR_W   = 13;       // wall opening, X — fits plug + boot
USBC_PLUG_CLEAR_H   = 8;        // wall opening, Z
USBC_PLUG_CLEAR_R   = 1;        // corner rounding on the wall opening

// =============================================================================
// Layout positions duplicated from parts/layout_front.scad.
// MUST match the layout file. If you change positions there, update here too.
// =============================================================================
DISPLAY_POS         = [0, 12];

JOYSTICK_X          = 85;
JOYSTICK_Y          = DISPLAY_POS.y;

TOGGLE_Y            = 45;
TOGGLE_SPACING_X    = 18;
TOGGLE_CLUSTER_OFF  = 102;
TOGGLE_LEFT_X       = [-TOGGLE_CLUSTER_OFF - TOGGLE_SPACING_X,
                       -TOGGLE_CLUSTER_OFF,
                       -TOGGLE_CLUSTER_OFF + TOGGLE_SPACING_X];
TOGGLE_RIGHT_X      = [ TOGGLE_CLUSTER_OFF - TOGGLE_SPACING_X,
                        TOGGLE_CLUSTER_OFF,
                        TOGGLE_CLUSTER_OFF + TOGGLE_SPACING_X];

ILLUM_BTN_Y         = -32;
ILLUM_BTN_SPACING   = 18;
ILLUM_BTN_CLUSTER   = JOYSTICK_X;
ILLUM_BTN_LEFT_X    = [-ILLUM_BTN_CLUSTER - ILLUM_BTN_SPACING,
                       -ILLUM_BTN_CLUSTER,
                       -ILLUM_BTN_CLUSTER + ILLUM_BTN_SPACING];
ILLUM_BTN_RIGHT_X   = [ ILLUM_BTN_CLUSTER - ILLUM_BTN_SPACING,
                        ILLUM_BTN_CLUSTER,
                        ILLUM_BTN_CLUSTER + ILLUM_BTN_SPACING];

ENCODER_X           = 30;
ENCODER_Y           = -42;

NAV_BTN_Y           = ENCODER_Y;
NAV_BTN_SPACING     = 10;

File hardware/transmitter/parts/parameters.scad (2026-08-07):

// Global parameters for OpenDriveHub transmitter hardware.
// Every dimension used in parts/*.scad lives here. Derive; don't duplicate.

// --- Rendering quality ---
$fn = 64;

// --- Printer constraints ---
PRINT_BED      = [200, 200];   // primary printer; 220x220 and 300x300 also available
NOZZLE_DIAM    = 0.4;
MIN_WALL       = 1.2;          // 3 perimeters @ 0.4mm
LAYER_H        = 0.2;

// --- Fit tolerances (FDM, tune per printer) ---
FIT_SLIP       = 0.2;          // radial offset for slip fit
FIT_PRESS      = -0.08;        // radial offset for press fit
FIT_FREE       = 0.35;         // radial offset for free/clearance

// --- Heat-set insert pocket (M3, 4mm OD, 4mm length) ---
INSERT_M3_OD   = 4.0;
INSERT_M3_LEN  = 4.0;
INSERT_M3_POCKET_D = INSERT_M3_OD - 0.1;
INSERT_M3_POCKET_H = INSERT_M3_LEN + 0.5;

// --- Heat-set insert pocket (M2, 3mm OD, 4mm length) ---
INSERT_M2_OD   = 3.0;
INSERT_M2_LEN  = 4.0;
INSERT_M2_POCKET_D = INSERT_M2_OD - 0.1;
INSERT_M2_POCKET_H = INSERT_M2_LEN + 0.5;

// --- Assembly visualization ---
EXPLODE        = 0;            // 0 = assembled; >0 separates parts along Z for preview

// --- 2S LiPo pouch nominal dimensions (verify with calipers!) ---
// Used by parts/battery.scad and case/bottom_shell.scad battery compartment.
BATT_BODY      = [80, 35, 15]; // pouch body [x, y, z] in mm

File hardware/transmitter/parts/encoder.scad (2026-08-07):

// EC11 rotary encoder with integrated push-button.
//
// 5-pin through-hole: 3 encoder (A, B, C/common) + 2 SPST momentary push.
// Pressing the shaft down closes the integrated switch.
//
// IMPORTANT: Body/bushing dimensions vary between manufacturers. These
// numbers fit the most common EC11 family (Alps, Bourns, generic clones).
// Verify against your specific encoder with a caliper.
//
// Conventions:
//   - Origin: center of attachable bounding volume.
//   - +Z points along the shaft (user-facing).
//   - Anchor "panel" sits on the panel-mating face (body top).
//   - Anchor "terminals" sits at the tip of the solder pins (bottom).
//   - D-flat on shaft is on the +X side (for set-screw knob alignment).

include <BOSL2/std.scad>
include <parameters.scad>
include <utils.scad>

// ----- EC11+switch nominal dimensions (verify) -----
EC_BODY        = [12.5, 13.4, 6.5];   // body below panel [x, y, z]
EC_BUSH_D      = 7;                    // M7×0.75 threaded bushing OD
EC_BUSH_H      = 7;                    // bushing above body (clears panel + nut)
EC_NUT_AF      = 10;                   // hex panel nut across-flats
EC_NUT_H       = 1.5;
EC_SHAFT_D     = 6;                    // shaft OD
EC_SHAFT_L     = 20;                   // bushing-top to shaft-tip
EC_SHAFT_FLAT  = 0.5;                  // D-cut depth (0 = round shaft)
EC_PIN_ROW_Y   = 2.5;                  // gap between encoder-row and switch-row
EC_PIN_PITCH   = 2.5;                  // spacing between pins in a row
EC_PIN_L       = 3.5;                  // pin length below body
EC_PANEL_CUT   = 7.2;                  // panel cutout Ø (bushing + clearance)

module ec11_encoder(anchor=CENTER, spin=0, orient=UP) {
    total_z = EC_BODY.z + EC_PIN_L + EC_BUSH_H + EC_SHAFT_L;
    nut_od  = EC_NUT_AF / cos(30);
    size    = [max(EC_BODY.x, nut_od), max(EC_BODY.y, nut_od), total_z];
    anchors = [
        named_anchor("panel",     [0, 0, -size.z/2 + EC_BODY.z + EC_PIN_L], UP),
        named_anchor("terminals", [0, 0, -size.z/2], DOWN),
    ];
    attachable(anchor, spin, orient, size=size, anchors=anchors) {
        down(size.z/2 - EC_BODY.z - EC_PIN_L)
            _ec11_geometry();
        children();
    }
}

module _ec11_geometry() {
    // Body (below panel)
    color(COLOR_PLASTIC)
        down(EC_BODY.z)
            cuboid(EC_BODY, anchor=BOTTOM);

    // Pin array: encoder row (3 pins) + switch row (2 pins)
    color(COLOR_BRASS)
        down(EC_BODY.z + EC_PIN_L/2) {
            back(EC_PIN_ROW_Y/2)
                for (x = [-EC_PIN_PITCH, 0, EC_PIN_PITCH])
                    translate([x, 0, 0])
                        cuboid([0.6, 0.6, EC_PIN_L]);
            fwd(EC_PIN_ROW_Y/2)
                for (x = [-EC_PIN_PITCH/2, EC_PIN_PITCH/2])
                    translate([x, 0, 0])
                        cuboid([0.6, 0.6, EC_PIN_L]);
        }

    // Threaded bushing
    color(COLOR_METAL)
        cyl(d=EC_BUSH_D, l=EC_BUSH_H, anchor=BOTTOM);

    // Hex panel nut (shown sitting on body-top for clarity)
    color(COLOR_METAL)
        up(EC_NUT_H/2)
            zrot(30)
                cyl(d=EC_NUT_AF / cos(30), l=EC_NUT_H, $fn=6, anchor=CENTER);

    // Shaft with optional D-flat on +X side
    up(EC_BUSH_H)
        color(COLOR_METAL)
            difference() {
                cyl(d=EC_SHAFT_D, l=EC_SHAFT_L, anchor=BOTTOM);
                if (EC_SHAFT_FLAT > 0)
                    translate([EC_SHAFT_D/2 - EC_SHAFT_FLAT, 0, EC_SHAFT_L/2])
                        cuboid([EC_SHAFT_D, EC_SHAFT_D + 2, EC_SHAFT_L + 0.2], anchor=LEFT);
            }
}

// -----------------------------------------------------------------------------
// Panel cutout helper.
// -----------------------------------------------------------------------------
module ec11_encoder_panel_cutout(panel_thick=2) {
    translate([0, 0, -0.1])
        cyl(d=EC_PANEL_CUT, l=panel_thick + 0.2, anchor=BOTTOM);
}

// -----------------------------------------------------------------------------
// Standalone preview.
// -----------------------------------------------------------------------------
SHOW_STANDALONE = true;
SHOW_SECTION    = false;

if (SHOW_STANDALONE) {
    if (SHOW_SECTION) back_half(s=200) ec11_encoder();
    else ec11_encoder();
}

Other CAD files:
hardware/transmitter/case/assembly_check.scad
hardware/transmitter/case/battery_cover.scad
hardware/transmitter/case/battery_lid.scad
hardware/transmitter/case/bottom_shell.scad
hardware/transmitter/case/corner_test.scad
hardware/transmitter/case/nav_button_cap.scad
hardware/transmitter/case/top_shell.scad
hardware/transmitter/parts/battery.scad
hardware/transmitter/parts/button_illuminated.scad
hardware/transmitter/parts/button_tact.scad
hardware/transmitter/parts/display.scad
hardware/transmitter/parts/joystick.scad
hardware/transmitter/parts/layout_front.scad
hardware/transmitter/parts/pcb_main.scad
hardware/transmitter/parts/pcb_subpanel.scad
hardware/transmitter/parts/speaker.scad
hardware/transmitter/parts/toggle_switch.scad
hardware/transmitter/parts/usb_c.scad
hardware/transmitter/parts/usb_c_extension_cable.scad
hardware/transmitter/parts/utils.scad

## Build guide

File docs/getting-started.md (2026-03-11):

# Getting Started with OpenDriveHub

This guide walks you through building and flashing the transmitter firmware for
the first time.

---

## Prerequisites

### Software

- [PlatformIO](https://platformio.org/) IDE plugin for VS Code, or PlatformIO Core CLI
- Git

### Hardware (minimum)

- ESP32 development board (ESP32-DevKitC recommended)
- TCA9548A I²C multiplexer breakout
- ILI9341 320×240 SPI LCD with XPT2046 resistive touch controller
- At least one input module (switch, button, potentiometer, or encoder)
- USB cable for programming

---

## Step 1: Clone the Repository

```bash
git clone https://github.com/peterus/OpenDriveHub.git
cd OpenDriveHub
```

---

## Step 2: Wire the Transmitter Hardware

Follow the wiring diagram in `hardware/transmitter/README.md`.

**Minimum connections:**

| ESP32 Pin | Connects to |
|---|---|
| GPIO21 (SDA) | TCA9548A SDA |
| GPIO22 (SCL) | TCA9548A SCL |
| GPIO23 (MOSI) | ILI9341 SDI / XPT2046 DIN |
| GPIO19 (MISO) | ILI9341 SDO / XPT2046 DOUT |
| GPIO18 (SCK) | ILI9341 SCK / XPT2046 CLK |
| GPIO5 | ILI9341 CS |
| GPIO27 | ILI9341 DC |
| GPIO26 | ILI9341 RST |
| GPIO32 | ILI9341 Backlight |
| GPIO4 | XPT2046 CS |
| GPIO2 | XPT2046 IRQ |
| 3V3 | TCA9548A VCC, ILI9341 VCC, XPT2046 VCC |
| GND | TCA9548A GND, ILI9341 GND, XPT2046 GND |

Add 4.7 kΩ pull-up resistors from 3V3 to both SDA and SCL lines.

---

## Step 3: Plug In a Module

Connect a module to **Slot 0** (TCA9548A channel 0 – SD0/SC0 pins).
See `hardware/modules/*/README.md` for individual module wiring.

---

## Step 4: Configure (optional)

Edit `firmware/lib/odh-config/Config.h` if your hardware differs from
the defaults (e.g. different GPIO pins, mux address, or slot count).

Configuration is organised as `inline constexpr` values in the
`odh::config` namespace:
- `odh::config::tx::` – transmitter-specific settings (LCD pins, slot count, etc.)
- `odh::config::rx::` – receiver-specific settings (PCA9685 address, channel count, etc.)
- `odh::config::` – shared settings (radio channel, failsafe timeout, battery ADC, etc.)

---

## Step 5: Build and Flash

```bash
cd firmware
pio run -e transmitter -t upload
```

Open the serial monitor at 115 200 baud to see startup messages:

```
[ODH] OpenDriveHub transmitter starting...
[ODH] Display OK
[ODH] Backplane mux OK
[ODH] Modules detected: P.....
[ODH] Radio (ESP-NOW) OK
[ODH] Scanning for vehicles...
```

---

## Step 6: Connect to a Receiver

OpenDriveHub uses **receiver-initiated discovery**.  Each receiver periodically
broadcasts an announcement containing its vehicle name and model type.  The
transmitter scans for these announcements and shows discovered vehicles on the
touch screen.

1. Power on the receiver.  It begins broadcasting its presence automatically.
2. Power on the transmitter.  The display enters scan mode and lists
   discovered vehicles as they appear.
3. Tap the vehicle you want to control on the touch screen.
4. The transmitter sends a bind packet and the link is established within a
   few seconds.
5. The display switches to control mode (channel bars + telemetry).

To disconnect, tap the **Disconnect** button on the control screen.  The
transmitter returns to scan mode and the receiver resumes announcing.

---

## Step 7: Web Configuration

Both the transmitter and receiver start a WiFi configuration interface
**automatically at every boot** – no button press required.

### Transmitter

1. The transmitter starts a WiFi Access Point:
   - SSID: `ODH-<DeviceName>` (default `ODH-TX`)
   - Password: `opendrv1`
2. Connect your phone or laptop to this network.
3. Open `http://192.168.4.1` in a browser.
4. Adjust settings and click **Save**.

### Receiver

1. The receiver starts a WiFi Access Point:
   - SSID: `ODH-Receiver-Config`
   - Password: `odhrecv1`
2. Connect to this network and open `http://192.168.4.1`.
3. Configure the vehicle name, model type, and function-to-channel mapping.

> **Note:** The transmitter and receiver each run their own independent AP.
> You can only connect to one at a time from a single device.

---

## Step 8: Running the Simulation (no hardware needed)

The simulation builds the full firmware for Linux, replacing hardware
peripherals with software shims (SDL2 display, UDP radio, pthreads).

### Prerequisites

```bash
sudo apt install pkg-config libsdl2-dev
```

### Run

Open two terminals:

```bash
cd firmware

# Terminal 1 – receiver
pio run -e sim_rx -t exec

# Terminal 2 – transmitter (headless terminal simulation)
pio run -e sim_tx -t exec

# Optional: transmitter with SDL2 GUI (requires libsdl2-dev)
pio run -e sim_tx_gui -t exec
```

The receiver starts announcing immediately.  The headless transmitter simulation
runs in the terminal.  For a graphical display, use `sim_tx_gui` which opens an
SDL2 window showing the scan screen.  After a few seconds the vehicle appears as
a button – click it to connect.

The web config UI is also available in simulation:
- Transmitter: `http://localhost:8080`
- Receiver: `http://localhost:8081`

See **[firmware/sim/README.md](../firmware/sim/README.md)** for the full keyboard
reference, connection flow, and known limitations.

---

## Running the Native Tests

Tests for the protocol utilities, function mapping, and display helpers run on
your host machine (no hardware needed):

```bash
cd firmware
pio test -e native
```

Expected output:
```
test/test_native/test_protocol.cpp:…
test/test_native/test_function_map.cpp:…
test/test_native/test_display.cpp:…
…
90 test cases: 90 succeeded
```

---

## Next Steps

- Add more modules – plug one into each slot and reboot; they are detected
  automatically.
- Read `docs/architecture.md` for an overview of the firmware design.
- Read `docs/protocol.md` for the radio protocol specification.
- Read `docs/backplane.md` for backplane and module slot details.

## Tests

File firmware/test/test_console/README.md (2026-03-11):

# OpenDriveHub Console Tests

End-to-end integration tests for the ODH interactive shell (`odh-shell`).
The framework launches simulation binaries or connects to real hardware via
serial and sends commands through the same console interface a human operator
would use.

---

## Prerequisites

- **Python 3.10+**
- **PlatformIO Core CLI** (for building simulation binaries)

Install the Python dependencies:

```bash
cd firmware/test/test_console
pip install -r requirements.txt
```

The two packages are:

| Package | Purpose |
|---|---|
| `pytest` | Test runner and assertion framework |
| `pyserial` | Serial transport for real hardware |

---

## Quick Start

```bash
cd firmware/test/test_console

# Run all tests against the receiver simulation (builds automatically)
pytest --target=sim_rx -v

# Run all tests against the transmitter simulation
pytest --target=sim_tx -v
```

On first run, pytest triggers `pio run -e sim_rx` (or `sim_tx`) to build the
binary. Skip with `--no-build` if you already built it:

```bash
pytest --target=sim_rx --no-build -v
```

---

## CLI Options

| Option | Default | Description |
|---|---|---|
| `--target=TARGET`  | `sim_rx`  | Which target to test (see table below) |
| `--port=PORT` | — | Serial port for hardware targets |
| `--build` | enabled | Build sim binary before tests (default) |
| `--no-build` | — | Skip the build step |

### Available Targets

| Target | Transport  | Description |
|---|---|---|
| `sim_rx` | PTY | Receiver simulation (subprocess) |
| `sim_tx` | PTY | Transmitter simulation (subprocess) |
| `serial_rx`  | Serial | Receiver on real hardware via UART |
| `serial_tx`  | Serial | Transmitter on real hardware via UART |

### Examples

```bash
# Receiver simulation – verbose output
pytest --target=sim_rx -v

# Transmitter simulation – only startup tests
pytest --target=sim_tx -v test_startup.py

# Real receiver hardware
pytest --target=serial_rx --port=/dev/ttyUSB0 -v

# Run a single test
pytest --target=sim_rx -v test_help.py::TestHelp::test_help_lists_status

# Show print output from tests
pytest --target=sim_rx -v -s
```

---

## Test Structure

```
firmware/test/test_console/
├── conftest.py               # Fixtures, CLI options, markers
├── console.py                # Console helper (send_command, wait_for_prompt)
├── transport.py              # SimTransport (PTY) + SerialTransport (pyserial)
├── requirements.txt          # Python dependencies
├── README.md                 # This file
├── test_startup.py           # Startup banner, prompt, exit/shutdown
├── test_help.py              # help command lists all expected entries
├── test_commands_common.py   # Commands shared by RX + TX
├── test_commands_rx.py       # Receiver-only commands
└── test_commands_tx.py       # Transmitter-only commands
```

### Test Files

| File | Tests | Description |
|---|---|---|
| `test_startup.py` | 5 | Prompt appears, no errors, banner, `exit` (sim) |
| `test_help.py` | 10 | `help` lists all registered commands |
| `test_commands_common.py` | 13 | `status`, `config`, `channel`, unknown/empty input  |
| `test_commands_rx.py` | 5 | `vehicle` get/set, `channel set` valid/invalid |
| `test_commands_tx.py` | 8 | `bind`, `trim`, `module`, `disconnect` |

---

## Architecture

### Transport Layer (`transport.py`)

The abstract `Transport` class defines the I/O interface. Two implementations
exist:

- **`SimTransport`** – Launches the simulation binary under a **PTY**
  (pseudo-terminal). This is necessary because the ODH simulation detects
  piped stdout via `isatty()` and redirects output to `/dev/tty`. Using a PTY
  makes `isatty()` return `true`, so all output goes through the captured
  stream.

- **`SerialTransport`** – Opens a serial connection via `pyserial` at 115200
  baud. A background thread continuously reads incoming bytes into a buffer.

Both transports provide:

```python
transport.start()                            # Open connection / launch process
transport.stop()                             # Close connection / kill process
transport.write(b"help\n")                   # Send raw bytes
transport.read_until("odh> ", timeout=5.0)   # Read until pattern
transport.read_available(timeout=0.5)        # Read whatever is buffered
transport.exit_code                          # Process exit code (sim only)
```

### Console Helper (`console.py`)

The `Console` class wraps a transport and provides command-level methods:

```python
console.start(startup_timeout=10.0)   # Start + wait for first prompt
console.startup_output                 # Everything printed before first prompt
console.send_command("status")         # Send command, wait for prompt, return output
console.send_raw(b"\x1b[A")           # Send raw bytes (e.g. arrow keys)
console.stop()                         # Shut down
```

`send_command()` automatically:
1. Appends `\n` and sends the command
2. Waits for the next `odh> ` prompt
3. Strips the echoed command line from the output
4. Returns only the command's response text

### Fixtures (`conftest.py`)

| Fixture | Scope | Description |
|---|---|---|
| `console` | module | Ready `Console` instance (prompt received) |
| `target` | session  | Target string (e.g. `"sim_rx"`) |
| `target_type` | session  | `"rx"` or `"tx"` |
| `is_sim` | session  | `True` for simulation targets |

The `console` fixture is **module-scoped**: one process per test file. This
keeps tests fast (~5 seconds for all 41 tests) while still isolating test
modules from each other.

### Markers

| Marker | Effect |
|---|---|
| `@pytest.mark.rx` | Runs only on receiver targets |
| `@pytest.mark.tx` | Runs only on transmitter targets  |
| `@pytest.mark.sim_only` | Runs only on simulation targets |

Markers are applied automatically – tests with a wrong marker are skipped with
a descriptive reason.

---

## Writing New Tests

### 1. Basic Test

Every test receives the `console` fixture and uses `send_command()`:

```python
from console import Console

class TestMyFeature:
    def test_something(self, console: Console) -> None:
        output = console.send_command("my_command arg1 arg2")
        assert "expected text" in output
```

`send_command()` returns the shell output as a string (without echo and
prompt). Use standard `assert` statements to validate the response.

### 2. Target-Specific Tests

Use markers to restrict tests to receiver or transmitter:

```python
import pytest

pytestmark = pytest.mark.tx   # All tests in this file are TX-only

class TestTransmitterFeature:
    def test_bind_status(self, console: Console) -> None:
        output = console.send_command("bind list")
        assert "error" not in output.lower()
```

Or mark individual tests:

```python
class TestMixed:
    @pytest.mark.rx
    def test_vehicle_name(self, console: Console) -> None:
        output = console.send_command("vehicle")
        assert len(output.strip()) > 0

    @pytest.mark.tx
    def test_trim_value(self, console: Console) -> None:
        output = console.send_command("trim list")
        assert len(output.strip()) > 0
```

### 3. Simulation-Only Tests

For tests that can't run on real hardware (e.g. killing the process):

```python
@pytest.mark.sim_only
def test_exit_terminates(self, console: Console) -> None:
    console.send_raw(b"exit\n")
    time.sleep(1.0)
    assert console.exit_code == 0
```

### 4. Testing Set/Get Roundtrips

A common pattern is to set a value, read it back, then restore the original:

```python
def test_config_roundtrip(self, console: Console) -> None:
    # Save original
    original = console.send_command("config get")

    # Set new value
    console.send_command("config set batt_cell 3")

    # Verify
    output = console.send_command("config get")
    assert "3" in output

    # Restore
    console.send_command("config set batt_cell 0")
```

### 5. Testing Error Responses

Verify that invalid input produces an error message (not a crash):

```python
def test_invalid_argument(self, console: Console) -> None:
    output = console.send_command("channel set 0 99999")
    out_lower = output.lower()
    assert any(kw in out_lower for kw in ("error", "invalid", "must be", "range")), (
        f"Expected error message, got:\n{output}"
    )
```

### 6. Using the `startup_output` Property

To verify what the firmware prints before the shell prompt:

```python
def test_no_crash_on_startup(self, console: Console) -> None:
    assert "PANIC" not in console.startup_output.upper()
    assert "[ERROR]" not in console.startup_output.upper()
```

### 7. Fresh Process per Test (Shutdown Tests)

The `console` fixture is module-scoped (shared across one file). If a test
needs its own process (e.g. to test `exit`), create a transport manually:

```python
from conftest import TARGET_ENV_MAP, _sim_binary_path
from transport import SimTransport

@pytest.mark.sim_only
def test_exit_code(self, target: str) -> None:
    binary = _sim_binary_path(TARGET_ENV_MAP[target])
    transport = SimTransport(binary)
    con = Console(transport)
    con.start(startup_timeout=10.0)
    try:
        con.send_raw(b"exit\n")
        time.sleep(1.0)
        assert con.exit_code == 0
    finally:
        con.stop()
```

---

## Adding a New Test File

1. Create `test_my_feature.py` in `firmware/test/test_console/`
2. Add the GPL-3.0 copyright header (see existing files)
3. Import `Console` and use the `console` fixture
4. Add markers if tests are target-specific
5. Run: `pytest --target=sim_rx -v test_my_feature.py`

### Template

```python
# Copyright (C) 2026 Peter Buchegger
#
# This file is part of OpenDriveHub.
# ... (full GPL-3.0 header)
#
# SPDX-License-Identifier: GPL-3.0-or-later

"""Tests for <describe your feature>."""

from __future__ import annotations

import pytest

from console import Console

class TestMyFeature:
    """Describe what this test class verifies."""

    def test_basic_case(self, console: Console) -> None:
        output = console.send_command("my_command")
        assert "expected" in output.lower()

    @pytest.mark.rx
    def test_rx_specific(self, console: Console) -> None:
        output = console.send_command("vehicle")
        assert len(output.strip()) > 0
```

---

## Timeouts

| Scenario | Default Timeout | Where to Change |
|---|---|---|
| Startup | 10 s | `conftest.py` → `con.start(startup_timeout=…)` |
| Command response | 5 s | `console.send_command(cmd, timeout=…)` |
| Read available | 0.5 s | `console.read_available(timeout=…)` |

For real hardware, you may need longer timeouts. Override per-command:

```python
output = console.send_command("slow_command", timeout=15.0)
```

---

## Troubleshooting

### `TimeoutError: Timed out waiting for pattern 'odh> '`

- The simulation may not have started. Run `pio run -e sim_rx` manually to
  check for build errors.
- On serial: verify the port and baud rate (`115200`).
- Increase the timeout: `console.send_command("cmd", timeout=15.0)`.

### Tests fail with `FileNotFoundError: Simulation binary not found`

- Build the simulation first: `cd firmware && pio run -e sim_rx`
- Or remove `--no-build` to let pytest build automatically.

### Serial `--port` required error

- Hardware targets need `--port`: `pytest --target=serial_rx --port=/dev/ttyUSB0`

### PTY-related errors on macOS/Windows

- The `SimTransport` uses Linux PTY (`pty.openpty()`). On macOS this should
  work. Windows is not supported for simulation tests (use WSL).

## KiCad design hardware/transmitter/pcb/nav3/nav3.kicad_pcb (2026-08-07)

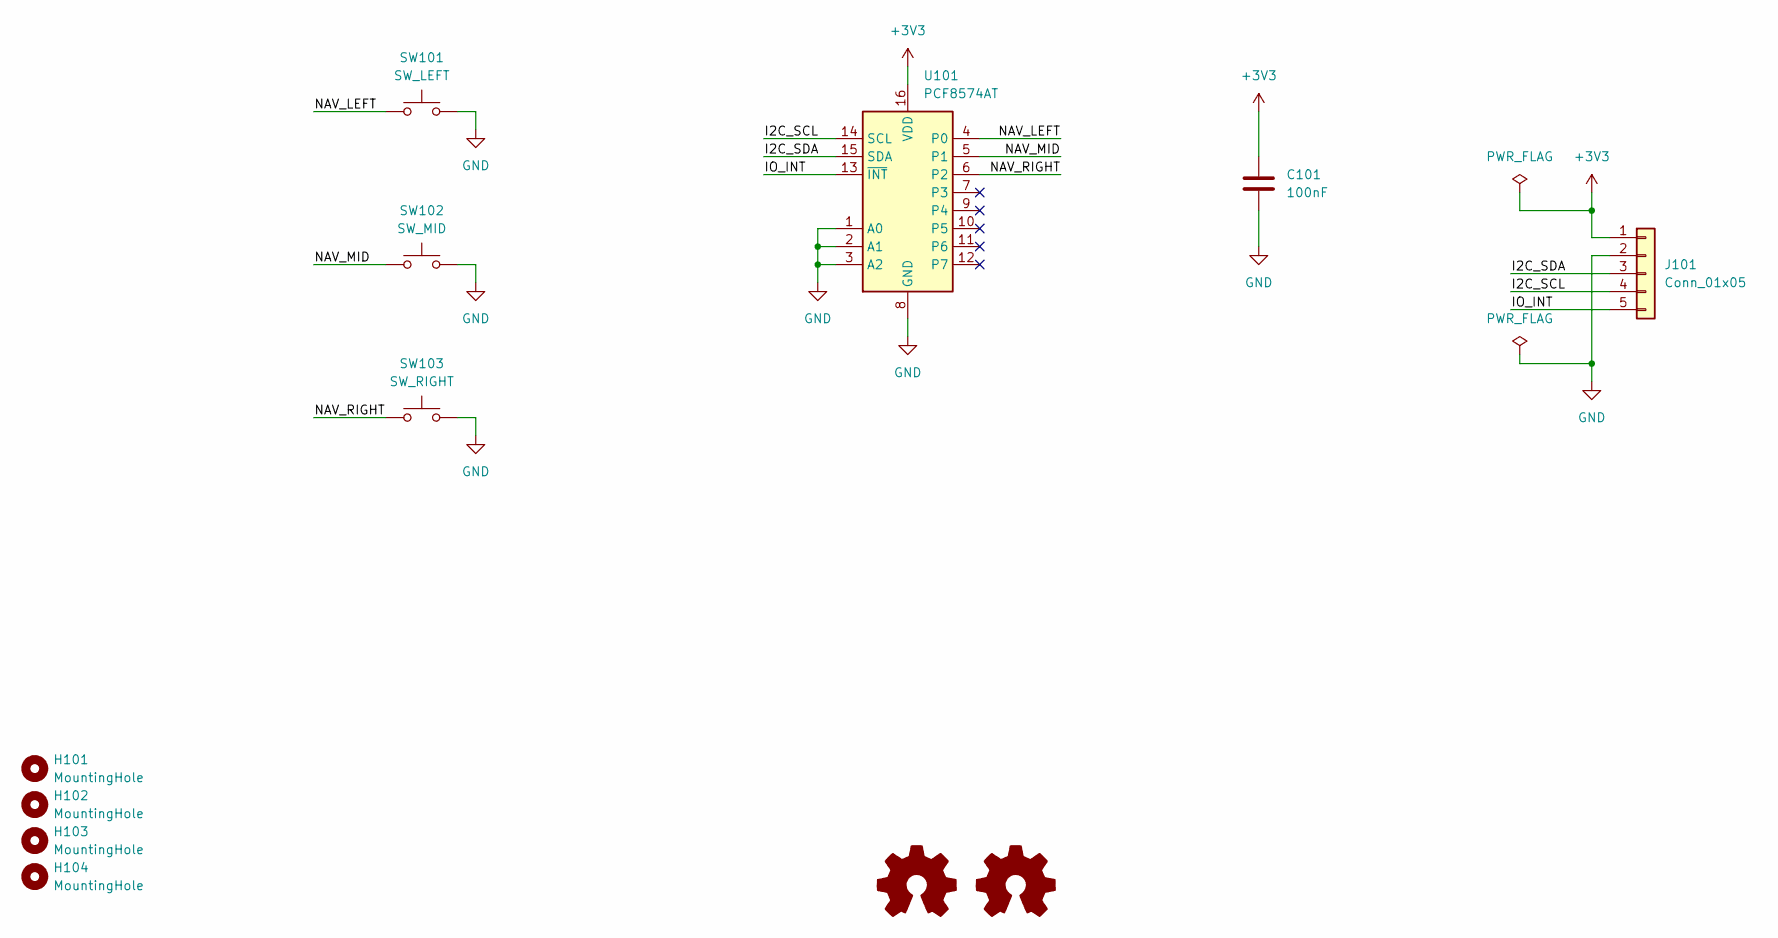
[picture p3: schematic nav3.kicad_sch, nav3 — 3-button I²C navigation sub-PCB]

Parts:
C101: 100nF; C_0805_2012Metric
H101, H102, H103, H104: MountingHole; MountingHole_2.2mm_M2
J101: Conn_01x05; JST_XH_B5B-XH-A_1x05_P2.50mm_Vertical
LOGO101, LOGO102: Logo_Open_Hardware_Small; OSHW-Logo_5.7x6mm_SilkScreen
SW101: SW_LEFT; SW_PUSH_6mm_H5mm
SW102: SW_MID; SW_PUSH_6mm_H5mm
SW103: SW_RIGHT; SW_PUSH_6mm_H5mm
U101: PCF8574AT; TSSOP-16_4.4x5mm_P0.65mm

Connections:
+3V3: C101.1, J101.1, U101.16 (VDD)
/I2C_SCL: J101.4, U101.14 (SCL)
/I2C_SDA: J101.3, U101.15 (SDA)
/IO_INT: J101.5, U101.13 (~INT)
/NAV_LEFT: SW101.1, U101.4 (P0)
/NAV_MID: SW102.1, U101.5 (P1)
/NAV_RIGHT: SW103.1, U101.6 (P2)
GND: C101.2, J101.2, SW101.2, SW102.2, SW103.2, U101.1 (A0), U101.2 (A1), U101.3 (A2), U101.8 (GND)

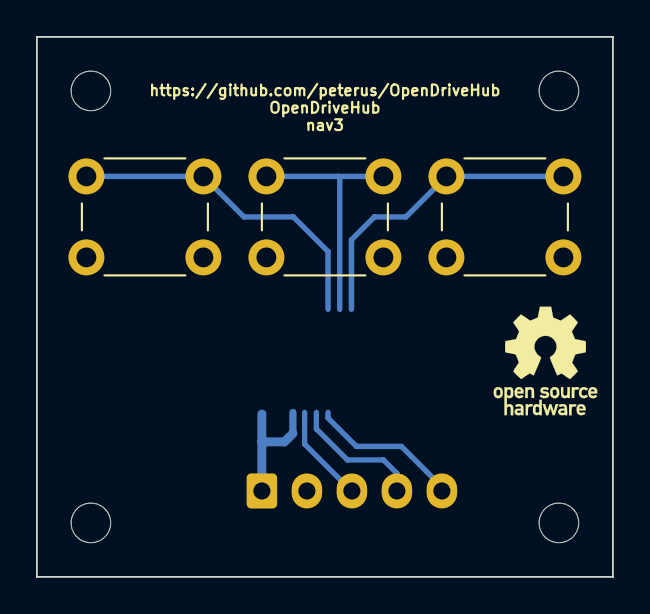
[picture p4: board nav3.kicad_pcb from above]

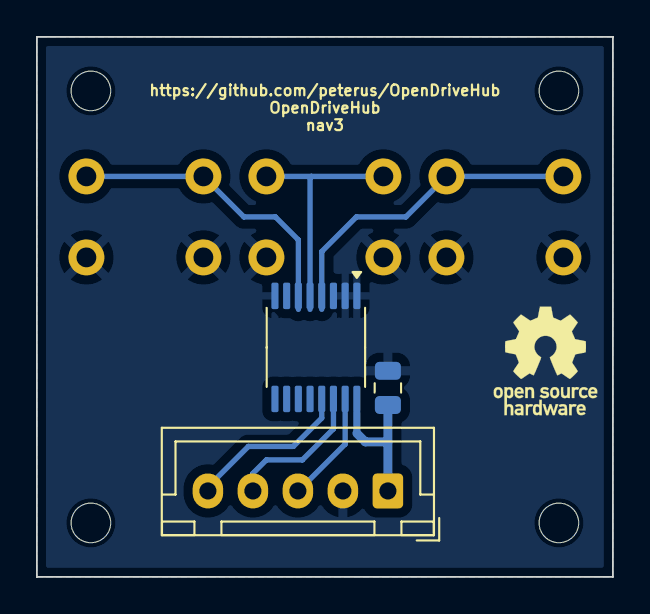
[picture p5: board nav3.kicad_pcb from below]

Board: 2 copper layers, 32.0 x 30.0 mm, 12 parts (4 on the bottom side), 8 nets.

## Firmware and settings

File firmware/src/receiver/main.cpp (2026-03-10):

/*
 * Copyright (C) 2026 Peter Buchegger
 *
 * This file is part of OpenDriveHub.
 *
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
 * SPDX-License-Identifier: GPL-3.0-or-later
 */

/**
 * OpenDriveHub – Receiver Firmware Entry Point
 *
 * Minimal main.cpp – all logic lives in ReceiverApp.
 */

#include "ReceiverApp.h"

#include <freertos/FreeRTOS.h>
#include <freertos/task.h>

static odh::ReceiverApp app;

void setup() {
    app.begin();
}

void loop() {
    vTaskDelay(pdMS_TO_TICKS(1000));
}

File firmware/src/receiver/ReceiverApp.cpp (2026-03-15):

/*
 * Copyright (C) 2026 Peter Buchegger
 *
 * This file is part of OpenDriveHub.
 *
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
 * SPDX-License-Identifier: GPL-3.0-or-later
 */

#include "ReceiverApp.h"

#include <Arduino.h>

#include <Channel.h>
#include <ChannelScanner.h>
#include <Shell.h>
#include <cstring>

#ifndef NATIVE_SIM
#include <Wire.h>

#include "output/Pca9685Output.h"
#else
#include "output/LoggingOutput.h"
#endif

#include "shell/ReceiverShellCommands.h"

namespace odh {

ReceiverApp::ReceiverApp()
    : _battery(config::kBatteryAdcPin, config::kBatteryDividerRatio, config::kAdcVrefMv, config::kAdcResolutionBits),
      _webServer(config::rx::kWebHttpPort),
      _api(_webServer, _output, _radio, _battery) {}

void ReceiverApp::begin() {
    Serial.begin(115200);
    Serial.println(F("[ODH-RX] OpenDriveHub receiver starting..."));

    // ── Create output drivers ───────────────────────────────────────
#ifndef NATIVE_SIM
    for (uint8_t i = 0; i < config::rx::kChannelCount; i++) {
        _output.setDriver(i, std::make_unique<Pca9685Output>(i));
    }
#else
    for (uint8_t i = 0; i < config::rx::kChannelCount; i++) {
        _output.setDriver(i, std::make_unique<LoggingOutput>(i));
    }
#endif

    // ── Load NVS configuration ──────────────────────────────────────
    _output.loadFromNvs();
    loadVehicleName();

    Serial.print(F("[ODH-RX] Model type: "));
    {
        auto name = modelName(_output.modelType());
#ifdef ODH_HAS_STRING_VIEW
        Serial.println(name.data());
#else
        Serial.println(name);
#endif
    }

    // ── Battery ADC ─────────────────────────────────────────────────
    _battery.begin();
    _battery.sample();
    _battery.autoDetectCells();

    // ── I²C + PCA9685 ───────────────────────────────────────────────
#ifndef NATIVE_SIM
    Wire.begin(config::kI2cSdaPin, config::kI2cSclPin, config::kI2cFreqHz);
    Pca9685Output::initChip(config::rx::kPca9685Addr);
    Serial.println(F("[ODH-RX] PCA9685 initialised"));
#endif

    // ── Outputs ─────────────────────────────────────────────────────
    _output.begin();
    Serial.println(F("[ODH-RX] Outputs initialised"));

    // ── Mutex ───────────────────────────────────────────────────────
    _channelsMux = xSemaphoreCreateMutex();

    // ── Radio ───────────────────────────────────────────────────────
    if (!_radio.begin([this](const ControlPacket &pkt) { onControlReceived(pkt); })) {
        Serial.println(F("[ODH-RX] Radio init failed – halting"));
        while (true)
            delay(1000);
    }
    Serial.println(F("[ODH-RX] Radio (ESP-NOW) OK"));

    // Register channel migration callback
    _radio.onChannelMigration([this](uint8_t newChannel) { onChannelMigration(newChannel); });

    // Configure presence parameters (but don't start yet)
    _radio.configurePresence(_vehicleName, static_cast<uint8_t>(_output.modelType()));

    // Run channel discovery to find an active transmitter
    runChannelDiscovery();

    // Re-register DiscoveryResponse callback for ongoing TX activity tracking
    _radio.onDiscoveryResponse([this](uint8_t /*ch*/, int8_t /*rssi*/, uint8_t /*devCount*/) {
        _lastTransmitterActivityMs = millis();
        _discoveryComplete         = true;
    });

    Serial.print(F("[ODH-RX] Active on channel "));
    Serial.println(_currentChannel);
    Serial.print(F("[ODH-RX] Presence broadcast: "));
    Serial.println(_vehicleName);

    // ── Web server + API ────────────────────────────────────────────
    {
        char ssid[33];
        snprintf(ssid, sizeof(ssid), "ODH-%s", _vehicleName);
        _webServer.begin(ssid, config::rx::kWebApPass, config::rx::kWebHttpPort);
    }
    _api.begin();
#ifndef NATIVE_SIM
    Serial.print(F("[ODH-RX] Web config AP IP: "));
    Serial.println(WiFi.softAPIP());
#else
    Serial.println(F("[ODH-RX] Web server started (simulation)"));
#endif

    // ── FreeRTOS tasks ──────────────────────────────────────────────
    xTaskCreatePinnedToCore(taskOutputFn, "output", config::rx::kTaskOutputStackWords, this, config::rx::kTaskOutputPriority, nullptr, config::rx::kTaskOutputCore);

    xTaskCreatePinnedToCore(taskTelemetryFn, "telemetry", config::rx::kTaskTelemetryStackWords, this, config::rx::kTaskTelemetryPriority, nullptr, config::rx::kTaskTelemetryCore);

    // ── Shell console ───────────────────────────────────────────────
    registerReceiverShellCommands(_shell, *this);
    xTaskCreatePinnedToCore(taskShellFn, "shell", config::kShellTaskStackWords, this, config::kShellTaskPriority, nullptr, config::kShellTaskCore);

    Serial.println(F("[ODH-RX] Setup complete"));
}

// ── Control packet callback ─────────────────────────────────────────────

void ReceiverApp::onControlReceived(const ControlPacket &pkt) {
    if (xSemaphoreTake(_channelsMux, 0) == pdTRUE) {
        _output.applyControl(pkt);
        _failsafeActive = false;
        xSemaphoreGive(_channelsMux);
    }
}

// ── FreeRTOS task wrappers ──────────────────────────────────────────────

void ReceiverApp::taskOutputFn(void *param) {
    static_cast<ReceiverApp *>(param)->runOutputLoop();
}

void ReceiverApp::taskTelemetryFn(void *param) {
    static_cast<ReceiverApp *>(param)->runTelemetryLoop();
}

void ReceiverApp::taskWebFn(void *param) {
    static_cast<ReceiverApp *>(param)->runWebLoop();
}

void ReceiverApp::taskShellFn(void *param) {
    static_cast<ReceiverApp *>(param)->runShellLoop();
}

// ── Output loop (50 Hz) ─────────────────────────────────────────────────

void ReceiverApp::runOutputLoop() {
    TickType_t lastWake = xTaskGetTickCount();

    for (;;) {
        const bool failsafe = (_radio.msSinceLastControl() > config::kRadioFailsafeTimeoutMs);

        if (failsafe && !_failsafeActive) {
            _output.applyFailsafe();
            _failsafeActive = true;
        }
        // Normal channel updates happen directly in onControlReceived.

        vTaskDelayUntil(&lastWake, pdMS_TO_TICKS(20)); // 50 Hz
    }
}

// ── Telemetry loop (10 Hz) ──────────────────────────────────────────────
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

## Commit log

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2026-03-10 Fix module _ready flag and add license-headers CI job
    - Add setReady() to IModule and call it in ModuleManager::scanAndInit()
    after successful begin(). Without this, modules were never marked
    ready, so inputCount() returned 0 and the web UI showed no inputs
    in the function mapping dropdowns.
    - Add license-headers CI job that checks all source, HTML, and Python
    files for the SPDX-License-Identifier: GPL-3.0-or-later marker.
    [ModuleManager.cpp]
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2026-03-11 Refactor receiver and transmitter commands for improved functionality and clarity
    - Updated NVS store initialization in ReceiverApi to use a more generic namespace.
    - Modified TransmitterShellCommands to enhance command help descriptions and add new commands for input and rescan functionalities.
    - Changed command syntax from "list" to "get" for channel and trim commands to align with new command structure.
    - Added new tests for config help, config reset, and model setting to ensure proper command functionality.
    - Implemented additional tests for mapping and failsafe commands to verify expected behavior.
    - Enhanced help command tests to include new commands and ensure comprehensive coverage.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
    [TransmitterApp.cpp]
2026-03-13 fix: address review comments - dangling callback ref, UDP multicast fan-out, thread-safe channel switch
    [ReceiverApp.cpp]
2026-03-13 fix: prevent RX discovery loop by adding periodic heartbeat requests
    The receiver was stuck in a discovery loop every 3 seconds because:
    1. runChannelDiscovery()'s RAII guard clears the onDiscoveryResponse
    callback to avoid dangling stack references
    2. No DiscoveryResponse packets arrive during presence mode (the TX only
    replies to DiscoveryRequests, which are only sent during scanning)
    3. _lastTransmitterActivityMs was never updated, so checkTransmitterLoss
    repeatedly triggered, causing unnecessary channel re-scans
    Fix: the RX now sends periodic DiscoveryRequest heartbeats while in
    presence mode (not bound). The TX auto-replies with DiscoveryResponse,
    keeping the activity tracker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
    [ReceiverApp.cpp]
2026-03-13 fix: clean up DiscoveryRequest callback in TransmitterApp
    [TransmitterApp.cpp]
2026-03-13 fix: generate unique MAC address for multiple simulation instances
    [sim_arduino.cpp]
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2026-03-14 Fix redundant grid_w/grid_d in module_zone.scad and improve clean-all in Makefile
    [module_zone.scad]
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2026-04-24 Restart transmitter hardware bottom-up with new OpenSCAD workflow
    - Remove hardware/transmitter/enclosure/ — flawed top-down design.
    Rebuilding from vitamins up; enclosure will come last.
    - Add openscad-hardware skill (.claude/skills/): workflow rules, BOSL2 +
    NopSCADlib cheatsheet, FDM tolerances, and pitfalls catalog.
    - Add .mcp.json registering quellant/openscad-mcp for render_perspectives,
    validate_scad, and analyze_model in the edit-check-render loop.
    - Add hardware/transmitter/parts/ with parameters.scad (printer/tolerance
    constants) and joystick.scad (D400X-R4 generic thumb joystick, parametric,
    BOSL2 anchors for downstream assembly).
    [assembly.scad, display_zone.scad, joystick.scad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]
2026-04-24 Harden OpenSCAD feedback loop
    - Add parts/utils.scad: color palette (COLOR_METAL/PCB/PLASTIC/...),
    print_bed_check() per-part bed-fit diagnostic, explode_shift() helper.
    - Elevate render-check gate in SKILL.md to a named non-negotiable section:
    validate_scad -> analyze_model (implicit CGAL manifold check) ->
    render_perspectives -> Read PNGs. Document the MCP output_format gotcha.
    - Add BOSL2 section-view cheatsheet (back_half/left_half/bottom_half) to
    libraries.md and a new pitfall entry for overlapping-solids bugs that
    renders hide but analyze_model catches (the 2mm overlap from last session).
    - joystick.scad: adopt COLOR_* constants; add SHOW_STANDALONE/SHOW_SECTION/
    SHOW_MOCK_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
    [joystick.scad, utils.scad]
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2026-04-24 Add case/ directory with first top-shell iteration
    - case/parameters.scad: case constants (WALL_T, TOP_DEPTH, CORNER_R,
    PANEL_T, screw-boss sizes) + layout positions duplicated from
    parts/layout_front.scad. Flagged with a MUST-match comment; we will
    factor out to a shared constants file if drift becomes an issue.
    - case/shell_top.scad: first top-shell geometry. Hollow rounded cuboid
    (CORNER_R=10, all edges except bottom-mating rounded), solid front
    panel slab with every component's panel-cutout helper subtracted at
    the layout position. No internal standoffs or split yet.
    - case/assembly_check.scad: renders the shell + layout together as a
    visual regression check for cutout al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
    [assembly_check.scad, parameters.scad, shell_top.scad]
2026-04-25 Taper the top shell, add rounded vertical corners; toggle X-ray view
    - case/parameters.scad: bump CORNER_R 5->14 (rounded vertical corners on
    the front face). Add TOP_EDGE_R reference (not yet used by shell_top).
    Add TAPER_X=6 / TAPER_Y=4 — front face is 12x8 mm wider than back.
    - case/shell_top.scad: replace cuboid with prismoid for the outer shell so
    the side walls slope inward toward the back. Inner cavity follows the
    same taper to keep the wall uniform-ish. Front-face edges are still
    sharp; combining the taper with rounded top edges via rounded_prism
    needs more work — left as a TODO comment.
    - case/assembly_check.scad: add SHELL_XRAY flag (default false). When on,
    the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
    [assembly_check.scad, layout_front.scad, parameters.scad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]
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2026-04-25 Revert to diff()/edge_profile for top-edge rounding; document F5/F6 caveat
    prismoid's rounding2 parameter affects the *vertical* edge rounding at
    the top end (varying it from rounding1 at the bottom to rounding2 at
    the top), not the four top-face edges as I had hoped. Trying it left the
    top-face edges sharp.
    Restore the BOSL2 diff() + edge_profile([TOP]) + mask2d_roundover
    approach which actually rounds the top-face edges. It does have one
    caveat: tagged-diff geometry only resolves correctly under F6 CGAL
    render — in F5 OpenCSG preview the mask appears as translucent overlay
    that can look like a gap or extra material. Documented inline in the
    shell_top module and added pitfall #11 to the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
    [shell_top.scad]
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2026-04-25 Flip taper direction so the case bulges at the mating rim (real belly)
    The previous "barrel" attempt had front-panel and back-panel widest with
    the mating rim narrowest — a wasp-waist shape, the OPPOSITE of a belly.
    Both shells now taper inward from the mating rim toward their outer
    panel face. The mating rim is the widest point (CASE_W x CASE_H, 286 x
    136mm), and both panels narrow by 2*TAPER_X / 2*TAPER_Y. Side-profile
    is now a hexagonal silhouette that bulges out in the middle.
    [bottom_shell.scad, shell_top.scad]
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2026-04-25 Battery compartment: bosses, interior lid, screws
    Bottom-shell now has 4 corner bosses inside (M3 inserts top + bottom):
    - Bottom inserts hold the exterior battery_cover screws (from outside).
    - Top inserts hold the battery_lid screws (from case interior). The lid
    prevents the LiPo from dropping into the case interior when the case
    is upside down or the cover is open.
    Geometry:
    - BATT_BOSS_OD = 7 mm (1.5 mm wall around 4 mm M3 insert pockets).
    - BATT_BOSS_OFFSET_X/Y = 45 / 22 — outside the 80x35 battery body with
    ~5 mm clearance, so the battery slides cleanly between the four bosses.
    - BATT_BOSS_HEIGHT = 16 mm (back-panel-interior up to lid level).
    - COVER and LID both 110x64x2 mm;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
    [assembly_check.scad, battery_cover.scad, battery_lid.scad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]
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2026-04-25 Add print clearance between battery cover and recess
    Cover and recess were dimensioned identically, which OpenSCAD merges into
    one surface (no visible gap to inspect) and would bind on print tolerance.
    Adds BATT_COVER_FIT (FIT_FREE per side in XY) and BATT_COVER_Z_GAP (0.3mm
    in Z), enlarges the recess accordingly, and shifts the cover position in
    the assembly check so the cover top sits the gap-amount below the panel
    exterior — making the fit visible and printable.
    [assembly_check.scad, bottom_shell.scad, parameters.scad]
2026-04-25 Add 4 case-corner screw bosses to fasten top↔bottom shells
    Bosses sit at (±129, ±56) so they merge into the side wall at the panel
    face (smallest cavity due to taper) for stability while staying clear of
    the cavity at the mating face. The top boss is kept short (13mm) so it
    clears the toggle-switch bodies that hang below the front panel; the
    bottom boss runs the full 32mm so the screw is supported all the way.
    Insert lives in the top-shell boss; screw enters from the back panel
    exterior, runs through the hollow bottom-shell boss, crosses the mating
    face, threads into the insert. M3 x 40 — 5mm thread engagement.
    Restructured shell_top to nest the cavity subtraction inside the union
    wi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
    [bottom_shell.scad, parameters.scad, shell_top.scad]
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2026-04-25 Add stiffener fins from each case-corner boss to the case walls
    Two fins per boss in cardinal directions toward the case corner walls,
    2.5mm long × 1.5mm thick × full boss height. Length is bounded by the
    14mm rounded outer corner at the panel face (smallest cavity due to
    taper) — going further would poke through.
    The fins cross the cavity wall at the panel face where the wall is
    closest to the boss; the merge gives the boss a real wall connection
    instead of standing as a free pillar. Top and bottom shells get the
    same treatment (mirrored at the mating face).
    Placement loop now rotates each boss by atan2(sy, sx) - 45° so the
    boss-internal +X/+Y fins always align with the corner walls.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
    [bottom_shell.scad, parameters.scad, shell_top.scad]
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2026-04-25 Reduce case depth, add battery to assembly, add section view
    - TOP_DEPTH 35→30, BOTTOM_DEPTH 35→25 (-15mm total). Joystick pin block
    spills 4mm into the bottom-shell cavity at the corner where nothing
    else lives; battery + slot walls + lid still fit in 22mm of bottom
    cavity.
    - battery.scad gets a show_wires parameter; wires are routed flexibly
    in real assembly so they don't need to be visualised.
    - assembly_check.scad now places the LiPo cell in its slot and exposes
    a SECTION variable ("x" / "y" / "none") that slices the assembly
    through the centre to inspect interior fit. Note: the section needs
    CGAL render (--render) to apply correctly to attachable() vitamin
    geometry;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
    [assembly_check.scad, battery.scad, parameters.scad]
2026-04-25 Add USB-C breakout vitamin + mounting in bottom shell
    New parts/usb_c_breakout.scad models the AliExpress 17mm-pitch USB-C
    female breakout PCB (link in file header). Only the 17mm hole pitch is
    confirmed from the listing; PCB outline / receptacle dims are typical
    values — verify with calipers against the actual part.
    Bottom shell gets:
    - 2 standoffs on the back-panel interior at the breakout's mounting hole
    positions, with M2 heat-set insert pockets (M2 insert constants added
    to parts/parameters.scad).
    - Cable cutout through the -Y side wall, cuboid extending past both wall
    surfaces so the taper doesn't matter.
    Position: USBC_POS_X=80, USBC_PCB_CENTER_Y=-50 — clear of battery slo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
    [assembly_check.scad, bottom_shell.scad, parameters.scad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]
2026-04-25 Switch USB-C from breakout PCB to panel-mount extension cable
    Rename usb_c_breakout.scad → usb_c_extension_cable.scad and rewrite for
    the AliExpress 17mm-pitch female-panel-mount + male-plug pigtail (link
    in file header). The user supplied this part; the breakout PCB design
    was based on a wrong assumption.
    Mount geometry:
    - Housing flange sits flush against the OUTER face of the bottom shell
    -Y wall.
    - 2 M2 screws come from outside, pass through wall clearance holes
    (2.4mm), thread into M2 heat-set inserts in bosses on the inner side
    of the wall.
    - USB-C cable cutout in the wall lines up with the receptacle opening.
    Bottom shell changes:
    - usbc_boss() module replaces usbc_standoff(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
    [assembly_check.scad, bottom_shell.scad, parameters.scad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]
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2026-04-25 Add the 2 mounting screw holes to the USB-C panel-mount housing
    Through-holes (Ø2.4mm M2 clearance) at 17mm pitch, going through the
    full housing depth. Visualises where the case-side screws actually pass
    into the housing.
    [usb_c_extension_cable.scad]
2026-04-25 Move USB-C adapter to inside the case, enlarge wall plug opening
    The panel-mount adapter has its own M2 nuts in the flange — screws come
    from outside, through wall clearance holes, and thread directly into the
    adapter. No bosses or inserts needed in the case wall.
    Wall opening enlarged from 9.4×3.7mm (just the metal connector) to
    13×8mm rounded so over-moulded plug boots on heavier USB-C cables fit
    without the user having to file the case.
    Removed:
    - usbc_boss() module + boss placement loop
    - USBC_INNER_Y, USBC_BOSS_OD, USBC_BOSS_H, USBC_OPENING_W, USBC_OPENING_H
    Added:
    - USBC_PLUG_CLEAR_W (13), USBC_PLUG_CLEAR_H (8), USBC_PLUG_CLEAR_R (1)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
    [assembly_check.scad, bottom_shell.scad, parameters.scad]
2026-04-25 Add PCB design brief for the parallel KiCad session
    Self-contained reference covering: project overview, system architecture
    (I2C bus + 7 PCF8574 sub-expanders), PCB list with sizing rationale,
    component dimensions for footprint creation, layout positions from
    layout_front.scad, cabling between boards, power/charging architecture,
    case-side constraints, and open questions to resolve before tape-out.
    Source of truth for dimensions remains the OpenSCAD code; this brief
    points at the relevant files and pulls the numbers KiCad work needs.
2026-04-26 Fix F6 (CGAL) rendering of imported PCB STL — fuse + render() wrap
    Two complementary fixes for the issue where F5 (OpenCSG preview) showed
    the imported nav3 PCB but F6 (CGAL) silently dropped most of the
    geometry (5998 facets out of 60192 in the fused result, with the
    warning "Object may not be a valid 2-manifold").
    step_to_stl.py: fuse all STEP solids into a single closed shell before
    tessellating. KiCad exports the PCB body, IC, JST connector, etc. as
    separate solids that share faces (SMD pad bottom touches PCB top).
    CGAL's Nef polyhedron representation rejects touching-but-not-
    overlapping solids as non-manifold and discards them. Fusing
    eliminates the shared faces. Result: 18 solids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
    [pcb_subpanel.scad]
2026-04-26 Add printed nav-button caps that poke through the panel
    The 6×6 mm tact switches have a built-in 2.5 mm plastic cap that ends
    0.5 mm below the panel exterior — fingers can't reach it through the
    6.8 mm panel hole. nav_button_cap.scad is a small printed cap that
    press-fits onto the tact button's built-in cap and sits ~2 mm proud of
    the panel.
    Cap geometry:
    - Ø6.1 mm shaft (FIT_FREE clearance in the 6.8 mm panel cutout)
    - 5 mm tall (top face 2 mm above panel exterior at z=+5)
    - 6 mm × 6 mm × 2.5 mm socket on the underside, FIT_PRESS interference
    with the tact cap → no glue needed
    assembly_check.scad places three of these at the NAV_BTN positions.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
    [assembly_check.scad, nav_button_cap.scad]
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2026-04-26 Refine PCB workflow: schematic = AI template, PCB layout = user
    Clarify the AI/user split based on actual nav3 experience: scripted
    PCB layout via kicad-mcp-pro is a dead end, so the user owns PCB
    layout entirely in the KiCad GUI. The AI's contribution stops at
    ERC-clean schematic + BOM + project scaffolding, and resumes at
    STEP export → STL → OpenSCAD case-fit verification.
    Added §9.6 with a step-by-step "start a new sub-PCB" procedure that
    uses pcb/nav3/ as a copy-paste template (project settings, design
    rules, schematic-side workaround scripts, project-local symbol
    library). Renamed the "lessons learned" section to §9.7 "Gotchas
    inherited from nav3" and dropped the dead PCB-placeme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
2026-08-07 Add nav3 — 3-button I²C navigation sub-PCB
    First of the seven front-panel sub-PCBs. A PCF8574A I/O expander reads
    three momentary tact switches and reports over I²C, with an open-drain
    /INT line so the main MCU does not have to poll.
    - 32 x 30 mm, two-layer
    - F.Cu (panel side): the three switches only, so nothing else can
    collide with the panel cutouts
    - B.Cu (case-interior side): expander, decoupling cap, 5-pin JST-XH,
    plus a solid GND pour
    - 4x M2 mounting holes, 3 mm inset from the corners
    - ERC- and DRC-clean
    nav3_local.kicad_sym holds a flattened copy of the PCF8574AT symbol
    (no `extends`) so the schematic resolves it standalone.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
    [nav3.kicad_pcb, nav3.kicad_sch]
2026-08-07 Document the nav3 bill of materials and net assignment
    Every part with its KiCad symbol and footprint, the full PCF8574A
    pin-to-net table, the JST-XH pinout and the mechanical envelope.
    Records two decisions worth not re-deriving later: the I²C pull-ups
    live on the main PCB (exactly once per bus, not per sub-PCB), and the
    0x38 address does not collide with the FT6236 touch controller because
    the transmitter runs two separate I²C buses.
2026-08-07 Feed the real nav3 board geometry into the panel layout
    nav3_actual.step is exported from the finished KiCad board and replaces
    the placeholder block in the OpenSCAD assembly, so the case-fit check
    runs against the geometry that will actually be manufactured.
    Placing it revealed an offset: the switch row sits 5 mm off the board
    centroid, and the STEP export negates Y on top of that. The PCB centroid
    therefore has to go 5 mm "south" of NAV_BTN_Y for the switch caps to
    line up with the panel cutouts.
    [layout_front.scad, nav3_actual.step]
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2026-08-07 Update the design brief for the GUI-driven KiCad workflow
    The five nav3 helper scripts and the empty design-rules file are gone,
    so the sections that told you to run and copy them no longer describe
    reality:
    - §9 layout tree listed four files that no longer exist
    - §9.6 bootstrap copied the scripts into every new board and ran two of
    them as step 2; replaced by a check that KiCad can load the schematic
    at all
    - §9.7 presented both MCP bugs as "just run the script"; now describes
    the bug and the fix that was applied, and records why the scripts must
    not be restored from history — they had drifted to a 32x24 mm outline
    and I2C address 0x3F, neither of which matches the finished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
2026-08-07 Upgrade the schematic sandbox to the KiCad 10 file format
    Opening the project in KiCad 10.0.5 rewrites it from format 20250114
    (KiCad 9) to 20260306. The change is purely structural: symbol counts and
    the full set of reference/value properties are byte-identical before and
    after on all three sheets, and the project still loads and runs ERC.
    KiCad 9 can no longer open these files. That is accepted here — the
    sandbox exists to work out the remaining sub-PCB circuits and there is no
    reason to hold it back. nav3 is deliberately left on the KiCad 9 format
    for now; converting the finished board is a separate decision.
    [buttons.kicad_sch, pot.kicad_sch, switches.kicad_sch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]
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2026-08-07 Add kicad-environment reference snapshot for 2026-08-07
    Records machine state at a specific moment: KiCad 10.0.5 (Flatpak) + 9.0.8 (system),
    MCP pro 3.30.1, and verified tool availability. Dated so claims with short half-lives
    can decay without contaminating the skill's permanent guidance.
2026-08-07 Add kicad-hardware SKILL.md with preflight, drop stale version facts
    Removes the four-month-old KiCad-9.0.7 / kicad-mcp-pro v2.4.x bug
    section (workarounds no longer apply; the scripts it referenced are
    gone) and adds a Preflight section that has the agent establish
    current versions and tool availability itself via kicad_get_version()
    rather than trusting durable prose. File-edit policy's tool list is
    trimmed to drop stale tool names, pointing to Preflight instead.
    Version-dependent facts now live in references/kicad-environment.md
    (Task 1), a dated snapshot the skill explicitly says to distrust.
2026-08-07 Fix review findings: drop MCP setup note and stale library counts
    Deletes the MCP setup note section entirely — it asserted a path
    (.mcp.json), a restart requirement, an env-var value
    (KICAD_MCP_PROFILE=agent_full), and a tool-availability claim about
    the "minimal" profile, all violating the no-version/path/tool-
    availability constraint. references/kicad-environment.md already
    carries the .mcp.json.example reference, the profile/mode table with
    current tool counts, and the tool-availability-at-startup note.
    Also fixes Library policy: removes the wrong symbol/footprint library
    counts (225/146, measured today as 223/155) and replaces the two
    absolute KiCad-9 install paths with a version-neu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
2026-08-07 Add division-of-labour section, rewrite schematic capture workflow
    Task 3 of the kicad-hardware skill rework: inserts a "Division of
    labour" section immediately after the prime directive, documenting
    the project's hardest-won lesson (schematic capture is the agent's
    job as a draft; PCB layout is the user's job in the GUI). Replaces
    steps 1-5 of the greenfield workflow with a seven-step schematic
    capture sequence built on the vendor's own workflow ordering, kept
    free of version/tool-availability/path claims per the skill's
    binding constraint. Steps 6-9 (PCB outline, placement, routing, DRC
    gate) are kept and renumbered 8-11.
2026-08-07 Restore footprint-assignment step dropped in prior revision
    The prior commit's ambiguity resolution replaced workflow items 1-5
    and named only items 6-9 (PCB outline, place, route, DRC gate) as
    survivors, which silently dropped the footprint-assignment step
    (original item 5) with nowhere to land. Restores it verbatim as item
    8, shifting outline/place/route/DRC-gate to 9-12. List now runs 1-12
    with no gap or repeat.
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2026-08-07 Trim kicad-hardware skill description to trigger conditions only
    The frontmatter description ended with a clause summarising the
    validation workflow. A description that summarises the workflow gets
    followed instead of the skill body, turning the body into
    documentation agents skip. Removed the summary clause, kept the two
    trigger conditions.
    Consistency pass otherwise confirmed clean: item 12's validation
    hand-off already matches the Division of labour grant, the
    PCB_DESIGN_BRIEF.md cross-reference resolves, no stale tool-name or
    version references remain in the skill files, and an end-to-end read
    found no guessing hazards worth fixing.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
2026-08-07 kicad-hardware: fix final-review findings on stale claims and phrasing
    - PCB_DESIGN_BRIEF.md §9.5/§9.7: dated caveat marking the kicad-mcp-pro
    v2.4.x / KiCad 9.0.7 observations as historical; extends-symbol and
    file-format load failures no longer reproduce as of 2026-08-07.
    - kicad-environment.md: note that the CLI wrapper governs the shell too
    (bare kicad-cli hits the 9.0.8 escape hatch; use kicad-cli-10 to
    validate work done through the MCP server); Known defects heading now
    states the version it was measured against.
    - SKILL.md: drop the stale numeric claims ("a third of the schematic
    tools", "three things") in favor of version-neutral phrasing.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

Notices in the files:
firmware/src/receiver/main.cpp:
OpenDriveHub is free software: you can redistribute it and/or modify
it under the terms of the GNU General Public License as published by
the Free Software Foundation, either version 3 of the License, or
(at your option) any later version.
